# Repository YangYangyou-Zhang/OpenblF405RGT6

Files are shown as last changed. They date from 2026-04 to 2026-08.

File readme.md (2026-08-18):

包含一个5v-dcdc（bec），一个大疆高清图传（可拓展4G数传）直插口，sbus接口，elrs接收机接口，gps接口，
icm42605/42688p（mpu6500）加速度计，SPL06（bmp280）气压计，12组PWM输出（支持dshut）。
目前已编译和兼容APM、INAV、BF、px4平台代码迁移工作进行中。
考虑到市面上大部分F405固件因为flash阉割功能，本飞控APM固件已支持空速管，光流计（包含测距仪），板载计算机外部激光雷达或视觉定位。
It includes a 5v-dcdc (bec), a DJI high-definition image transmission (expandable to 4G data transmission) direct plug-in port, SBUS interface, ELRS receiver interface, and GPS interface,
ICM42605/42688P (MPU6500) accelerometer, SPL06 (BMP280) barometer, 12 sets of PWM outputs (supporting DSHUT).
Currently, it has been compiled and is compatible with APM, INAV, BF, PX4 platform.
Considering that most F405 firmware on the market has been disabled of its flash function, our flight control APM firmware now supports airspeed tubes, optical flow meters (including rangefinders), and external lidar or visual positioning for on-board computers.

请注意，此飞控的PX4功能由于F405芯片组的flash空间问题进行了阉割，导致此飞控的PX4功能仅可用于探索性研究。bootloader与APM共用
Please note that the PX4 functionality of this flight control using the F405 chip group's flash space has been阉ced, so this flight control's PX4 functionality is only suitable for exploratory research.The bootloader and APM share the same firmware.

请注意，使用APM固件时，如果不使用sbus接收机想要释放uart2号串口用于接elrs接收机或者数传链路设备时，
需要修改参数表BRD_ALT_CONFIG 引脚功能复用值为1（默认为0）来禁用sbus和释放uart为通用模式。
由于没有黑匣子芯片（如果没有安装SD卡）需要设置LOG_BACKEND_TYPE = 0，禁用日志功能。
Please note that when using APM firmware, if you want to free up UART2 serial port for connecting an ELRS receiver or a telemetry link device without using an SBus receiver,
The parameter table BRD_ALT_CONFIG needs to be modified by setting the pin function multiplexing value to 1 (default is 0) to disable SBus and release UART to general-purpose mode.
Due to the absence of a black box chip (if no SD card is installed), it is necessary to set LOG_BACKEND_TYPE = 0 to disable the logging function

PCB_BOM:https://oshwhub.com/yangyangyou/stm32f405_bl_matekf405_te_copy
请注意:此电路板为matekf405_te的改进版本，固件并不兼容。
Please note: This circuit board is an improved version of matekf405_te, and the firmware is not compatible.

PCB_BOM:https://oshwhub.com/yangyangyou/project_qvbuwenu
新增小型化穿越机专用飞控板卡（OpenblF405MINI系列），包含完整OSD、SD卡黑匣子和各种接口（所有接口均按照BF官方接口标准设计），包含大疆高清图传直插x1、GPS直插接口x1、四合一电子调速器直插、
I2C直插（空速管、测距仪）、串口直插x2（推荐elrs+数传电台）
New miniaturized flight controller board for FPV racing drones (OpenblF405MINI series), featuring full OSD, SD card black box, and various interfaces (all designed to BF official interface standards), including DJI HD video transmission direct plug x1, GPS direct plug x1, 4-in-1 ESC direct plug, I2C direct plug (airspeed sensor, rangefinder), serial port direct plug x2 (recommended ELRS + telemetry radio).

OpenblF405MINI
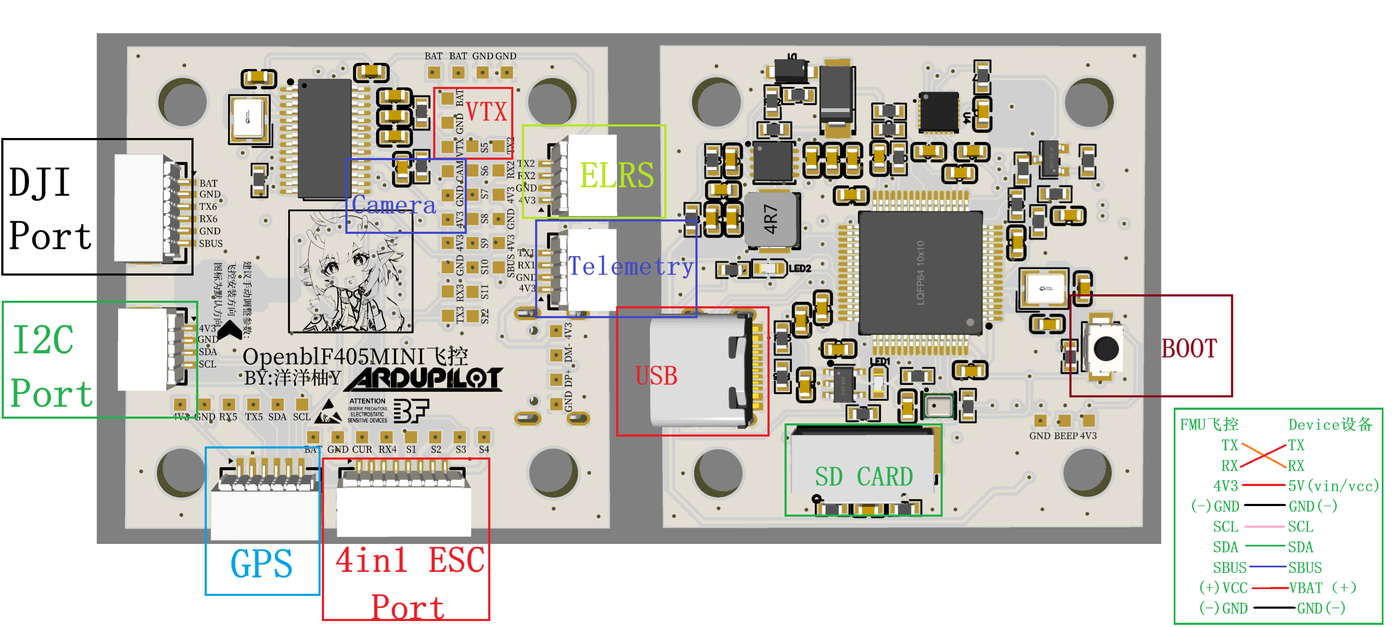
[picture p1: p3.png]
p3


OpenblF405RGT6
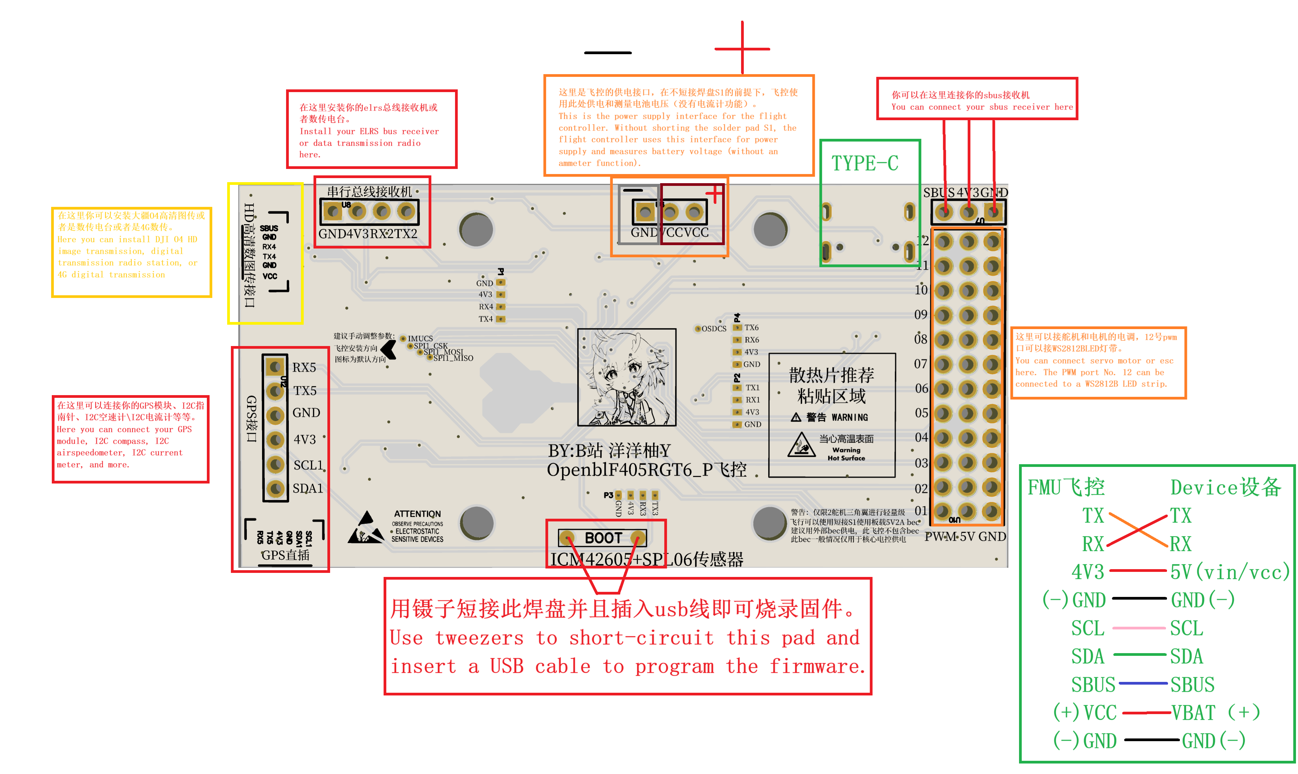
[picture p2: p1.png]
p1

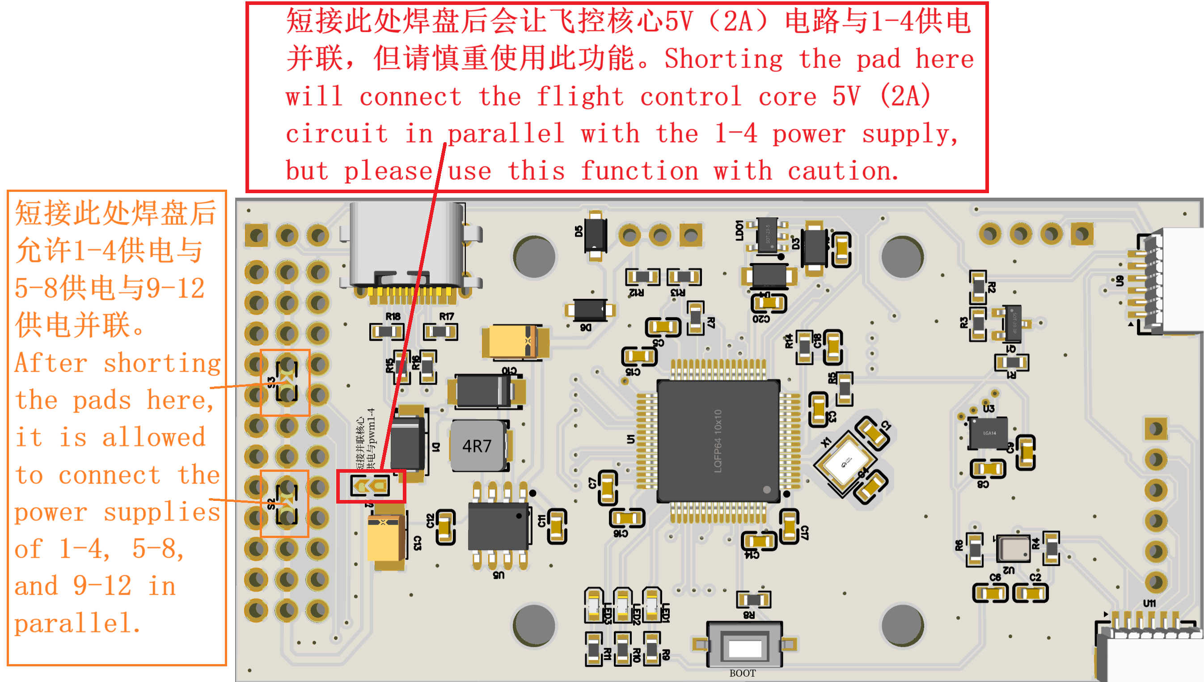
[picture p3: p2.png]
p2


代号说明Code Identifier Guide:
RGT6:40mmx80mm
MINI：40mmx40mm
(None)：mpu6500+bmp280
M：mpu6500+spl06
P：icm42605+spl06

如何快速入门APM：https://www.bilibili.com/video/BV1DJ7N61E1v

请注意，本设计为GPL3.0开源协议，允许商用，但需要标明原作者（洋洋柚/B站洋洋柚Y），无人机不是儿童玩具，使用时请遵守相关法律法规。
Please note that this design is under the GPL3.0 open-source protocol, which allows commercial use, but requires attribution to the original author (yangyangyou/bilibili 洋洋柚Y), and drones are not children's toys. Please abide by relevant laws and regulations when using it.

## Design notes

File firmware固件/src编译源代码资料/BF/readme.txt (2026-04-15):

# Update package list and upgrade system
sudo apt update && sudo apt upgrade

# Install basic compilation tools
# You need to install git (for cloning code), make (for building), clang (required for some tests), python, etc.
sudo apt -y install build-essential git curl clang-18 python3 python-is-python3

# Clone Betaflight source code
git clone https://github.com/betaflight/betaflight.git

# Enter the source code directory
cd betaflight

# Switch to a stable version (e.g. 4.5.3)
git checkout 4.5.3

# This command will automatically download and install the required toolchain
make arm_sdk_install

# After the first compilation or switching to a new branch, run this command to generate the default configuration for all target boards.
make configs

# Place the OpenblF405RGT6 folder into the ~/betaflight/src/config/configs directory, and then compile the OpenblF405RGT6 firmware
make config OpenblF405RGT6

# Find the compiled firmware betaflight_4.5.3_STM32F405_OpenblF405RGT6.hex in ~/betaflight/obj

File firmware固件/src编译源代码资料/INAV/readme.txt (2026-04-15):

# Clone iNav source code
git clone https://github.com/iNavFlight/inav.git
cd inav

# Create a build directory and initialize CMake
mkdir build && cd build
cmake

# Move the OpenblF405RGT6 folder to the directory ~/inav/src/main/target/.
# Compile firmware
cd ~/inav

# 1.  Create a build directory
mkdir -p build

# 2.  Run CMake configuration
cmake -B build -DCMAKE_TOOLCHAIN_FILE=cmake/toolchain-arm-none-eabi.cmake

# 3.  Compile your target (-j4 to compile with 4 CPU threads)
cmake --build build --target OpenblF405RGT6 -j4

# Check firmware
# Typically located in the ~/inav/build directory

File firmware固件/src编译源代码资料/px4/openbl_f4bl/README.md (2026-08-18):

# openbl_f4bl — PX4 固件编译说明

## 硬件平台
- **MCU**: STM32F405RGT6 (Cortex-M4, 168MHz, 1024KB Flash)
- **IMU**: MPU6500 (SPI1, CS=PA4, ROTATION_ROLL_180)
- **气压计**: BMP280 / SPL06 (I2C1, PB8/PB7)
- **OSD**: AT7456E (SPI1, CS=PB12)
- **LED**: PA14 (蓝), PA13 (绿)

## Flash 布局

| 区域 | 起始地址 | 大小 |
|---|---|---|
| Bootloader | `0x08000000` | 64KB (APM bootloader, ~16KB 实际) |
| 参数存储 | `0x08004000` | 16KB |
| 固件 | `0x08010000` | 960KB |

## 编译

### 1. 部署板级配置

```
cp -r openbl_f4bl /home/<username>/PX4-Autopilot/boards/openbl/f4bl
```

### 2. 应用框架补丁

PX4 框架 `io_timer.c` 需要打补丁以支持 TIM1/TIM8 高级定时器的互补通道 (CHxN) 输出。

文件: `platforms/nuttx/src/px4/stm/stm32_common/io_pins/io_timer.c`

补丁文件: `patches/io_timer.c` (完整的修改后文件)

修改内容:
- 在 `io_timer_channel_init()` 中，CCER 配置后添加互补输出使能 (CCxNE) 和互补极性 (CCxNP) 位
- 仅对 TIM1 和 TIM8 生效

```bash
cp patches/io_timer.c /home/<username>/PX4-Autopilot/platforms/nuttx/src/px4/stm/stm32_common/io_pins/io_timer.c
```

### 3. 编译固件

```bash
cd /home/<username>/PX4-Autopilot
make openbl_f4bl_default
```

### 4. 生成 HEX

```bash
arm-none-eabi-objcopy -O ihex build/openbl_f4bl_default/openbl_f4bl_default.elf openbl_f4bl_default.hex
```

## 产物

| 文件 | 说明 |
|---|---|
| `openbl_f4bl_default.bin` | 原始固件 (~888KB) |
| `openbl_f4bl_default.px4` | PX4 固件包 |
| `openbl_f4bl_default.hex` | Intel HEX 格式 |

## 修改文件清单

### 板级配置 (`boards/openbl/f4bl/`)

| 文件 | 说明 |
|---|---|
| `default.px4board` | PX4 模块/驱动/串口映射配置 |
| `firmware.prototype` | 固件元数据 (board_id=18880) |
| `init/rc.board_defaults` | 默认参数 (BAT, ATT_EN, SYS_HAS_MAG) |
| `init/rc.board_sensors` | 传感器启动脚本 (MPU6500, BMP280, SPL06) |
| `init/rc.board_extras` | OSD 启动脚本 |
| `src/board_config.h` | GPIO/ADC/PWM/LED 定义, BOARD_NUM_IO_TIMERS=3 |
| `src/timer_config.cpp` | PWM 定时器映射 (TIM8+TIM1+TIM2, 4 通道) |
| `src/spi.cpp` | SPI 总线设备声明 (MPU6500, OSD, SD) |
| `src/i2c.cpp` | I2C1 总线声明 |
| `src/init.c` | 板级初始化 (SPI, SD, Flash参数, ADC) |
| `src/led.c` | LED 控制 (PA14/PA13, 低电平有效) |
| `src/usb.c` | USB VBUS (始终报告在线) |
| `src/CMakeLists.txt` | 驱动编译定义 |
| `nuttx-config/include/board.h` | NuttX 时钟/引脚复用 (8MHz→168MHz) |
| `nuttx-config/include/board_dma_map.h` | DMA 流/通道分配 |
| `nuttx-config/nsh/defconfig` | NuttX 内核配置 |
| `nuttx-config/scripts/script.ld` | 链接脚本 (flash: 0x08010000, 960K) |

### PX4 框架修改

| 文件 | 说明 |
|---|---|
| `platforms/nuttx/src/px4/stm/stm32_common/io_pins/io_timer.c` | 添加 TIM1/TIM8 互补通道使能 (CCxNE+CCxNP) |

### NuttX Kconfig 路径修复 (编译环境相关)

| 文件 | 说明 |
|---|---|
| `platforms/nuttx/NuttX/apps/Kconfig` | 将 `/home/openbl/` 替换为 `/home/<username>/` |
| `platforms/nuttx/NuttX/apps/*/Kconfig` | 同上 (20 个子目录) |

## PWM 输出

| 通道 | 引脚 | 定时器 | 说明 |
|---|---|---|---|
| 1 | PC9 | TIM8_CH4 | 电机 1 |
| 2 | PC8 | TIM8_CH3 | 电机 2 |
| 3 | PB15 | TIM1_CH3N | 电机 3 (互补通道, 需框架补丁) |
| 4 | PA8 | TIM1_CH1 | 电机 4 |

## 串口映射

| 硬件 | 设备 | PX4 命名 |
|---|---|---|
| USART2 (PA2/PA3) | ttyS1 | TEL1 |
| UART5 (PC12/PD2) | ttyS2 | GPS1 |

## Bootloader

APM bootloader，基于 `hwdef-bl.dat` 编译。与 PX4 协议兼容。

构建:
```bash
cd /home/<username>/ardupilot
./waf configure --board OpenblF405RGT6 --bootloader
./waf bootloader
```

预编译 bootloader: `extras/openbl_f405_bootloader.bin`

## 烧录

```bash
# 首次: bootloader + 固件
STM32_Programmer_CLI -c port=usb1 -w extras/openbl_f405_bootloader.bin 0x08000000
STM32_Programmer_CLI -c port=usb1 -w openbl_f4bl_default.bin 0x08010000

# 仅固件 (QGC USB 直刷)
```

或 SD 卡: 将 `.px4` 复制到 SD 卡根目录，bootloader 自动刷写。

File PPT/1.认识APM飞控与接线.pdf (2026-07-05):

# 认识飞控板卡与接线

## 这里以OpenblF405RGT6为例

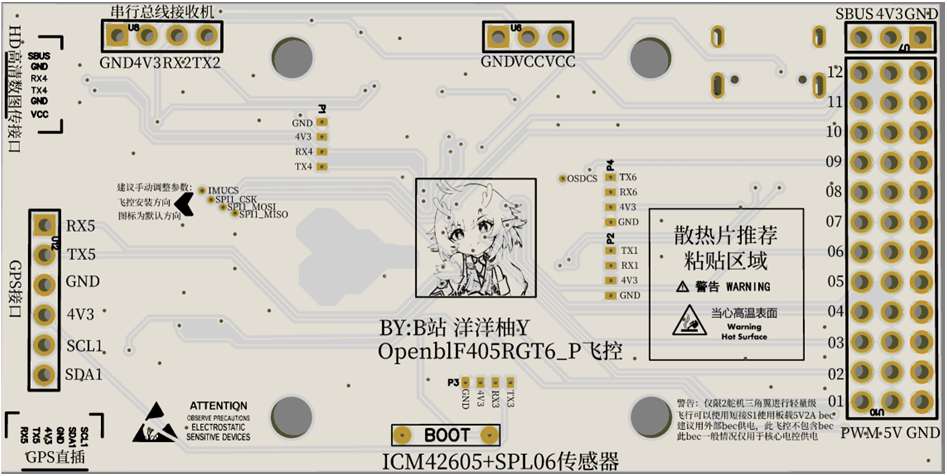
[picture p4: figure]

# 认识飞控板卡与接线

这里以OpenblF405RGT6为例

包含一个5v-dcdc（bec），一个大疆高清图传（可拓展4G数传）直插口，sbus接口， elrs接收机接口，gps接口，icm42605/42688p（mpu6500）加速度计，SPL06 （bmp280）气压计，12组PWM输出（支持dshut）。目前已编译和兼容APM、INAV、

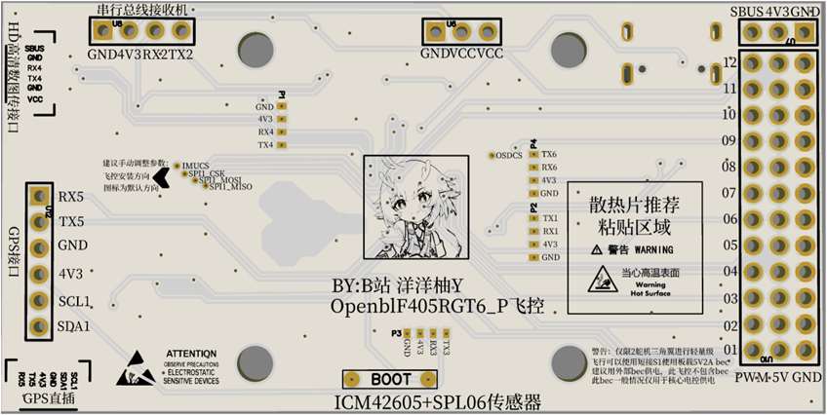
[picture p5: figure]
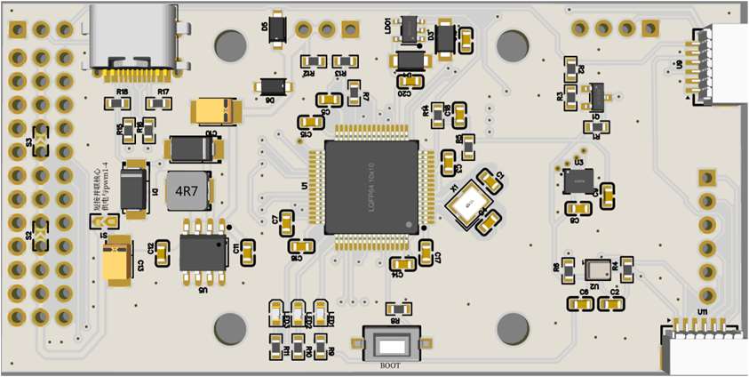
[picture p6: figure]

BF平台，px4平台代码迁移工作进行中。考虑到市面上大部分F405固件因为flash阉割 功能，本飞控APM固件已支持空速管，光流计（包含测距仪），板载计算机外部激光 雷达或视觉定位。

此飞控板卡完全开源，在符合开源协议且遵守当地相关法律法规的前提下可以随意使 用。

# 插口、焊盘、过孔焊盘（2.54）

2.54过孔焊盘可以直接焊接，
或者也可以焊接排针用于作为

支持端口使用，适合新手使用。

插口一般指的是可以直接将

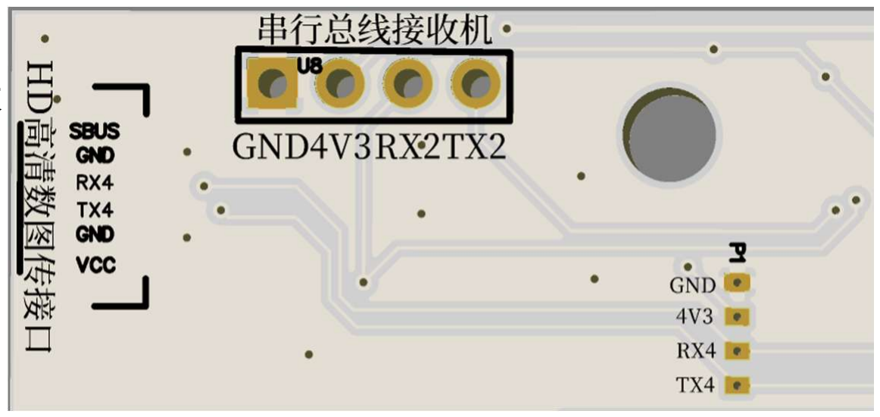
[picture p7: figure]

端子线排插插入的插口，一般
不需要焊接

普通焊盘只能直接焊接，
不适合焊接技术差的新手使用。

# 推荐新手使用过孔焊盘（2.54mm）

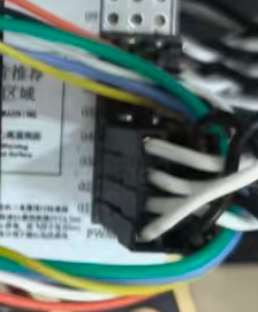
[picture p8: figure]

2.54过孔焊盘可以直接焊接，
或者也可以焊接排针用于作为
支持端口使用，适合新手使用。

焊接难度相对较低，对新手比较友
好，可以购买排针焊接到2.54过孔
焊盘使得可以直插设备。

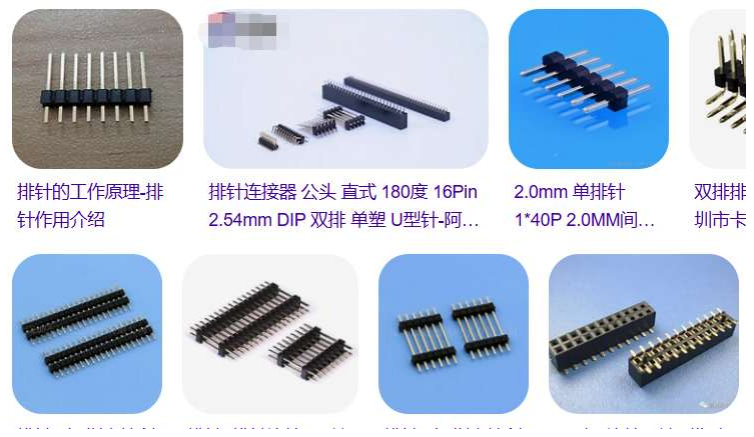
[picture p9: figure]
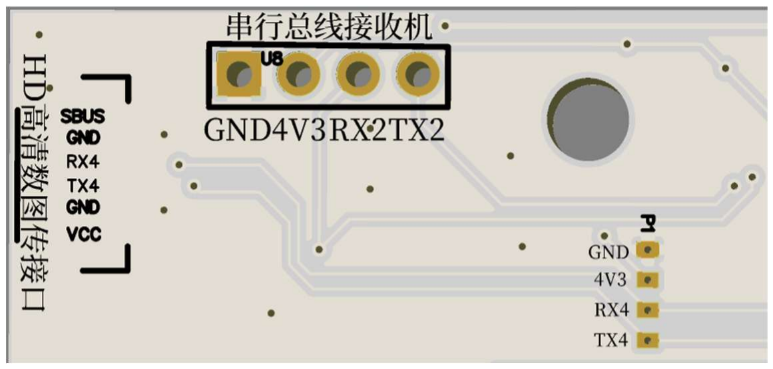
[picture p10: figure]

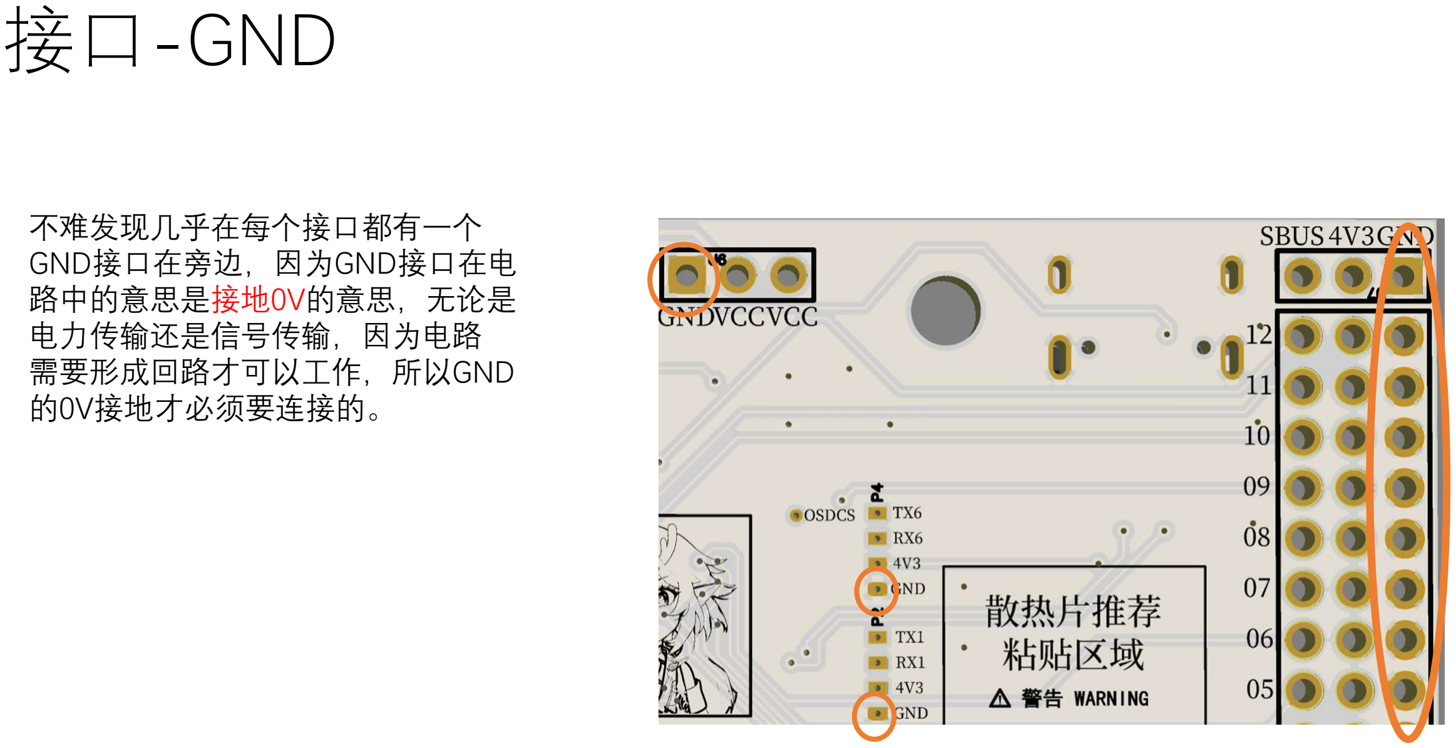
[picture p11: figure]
接口-GND; 不难发现几乎在每个接口都有一个 GND接口在旁边，因为GND接口在电 路中的意思是接地0V的意思，无论是 电力传输还是信号传输，因为电路 需要形成回路才可以工作，所以GND 的0V接地才必须要连接的。

# 接口-VBAT/VCC

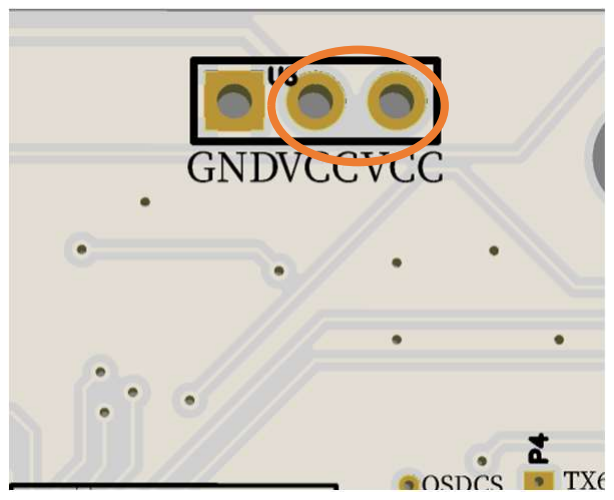
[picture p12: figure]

这个接口的名称在各个飞控板卡
的名字可能不同，例如这里叫VCC，
有些飞控叫vbat、bat，这个接口的
意思是指连接到动力电池的正极，
通常用于监测飞控电压，一般飞控
也会使用这个接口对飞控板卡供电，
同时当某些图传或者电台需要较高
的供电电压时，也会连接到这个接
口。

# 接口-5V

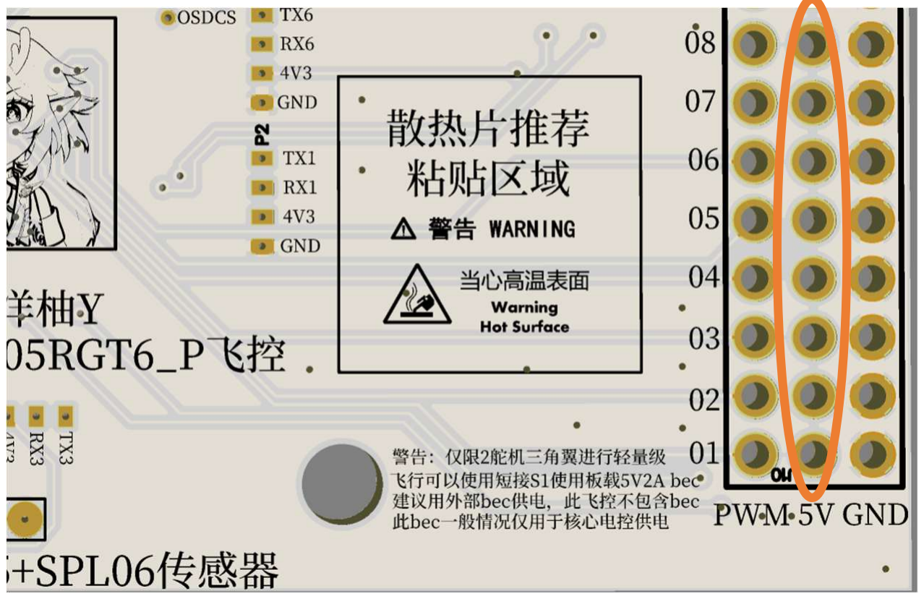
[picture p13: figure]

这个接口一般会由DCDC(bec)电路
提供+5V的电压，通常用于连接舵
机、电调等设备,但在部分飞控没
有bec电路时例OpenblF405RGT6 ，
需要连接带BEC功能的电调才可以
对舵机进行正常供电。

# 接口-4V3

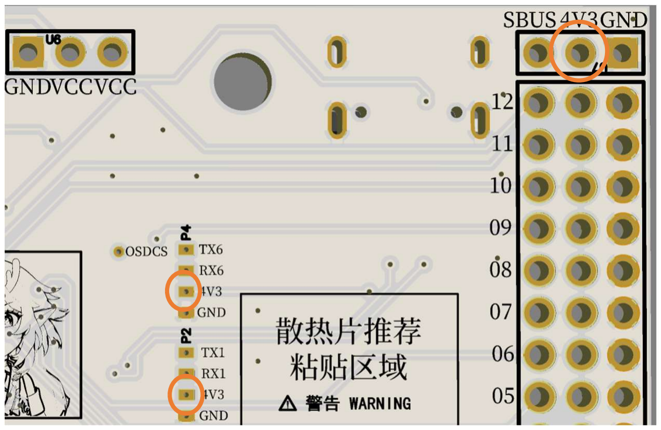
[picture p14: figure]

这个接口源于和5V同源且可以直接当
作5V接口使用，但这个接口一般在仅
连接电脑usb（不连接电池）时也会
供电，我们通常希望在调参时电机舵
机不会自己转动，但所有的传感器和
其他设备全部都要正常工作，因此会
在DCDC电路的5V接一个二极管到这
个4V3接口，因为二极管有压降，所
以电压略低于5V，如果仅使用usb连
接，一般5V电路不会工作（如舵机），
但4V3电路可以工作（如GPS、接收
机）。

# 接口-PWM、s1s2s3s4…

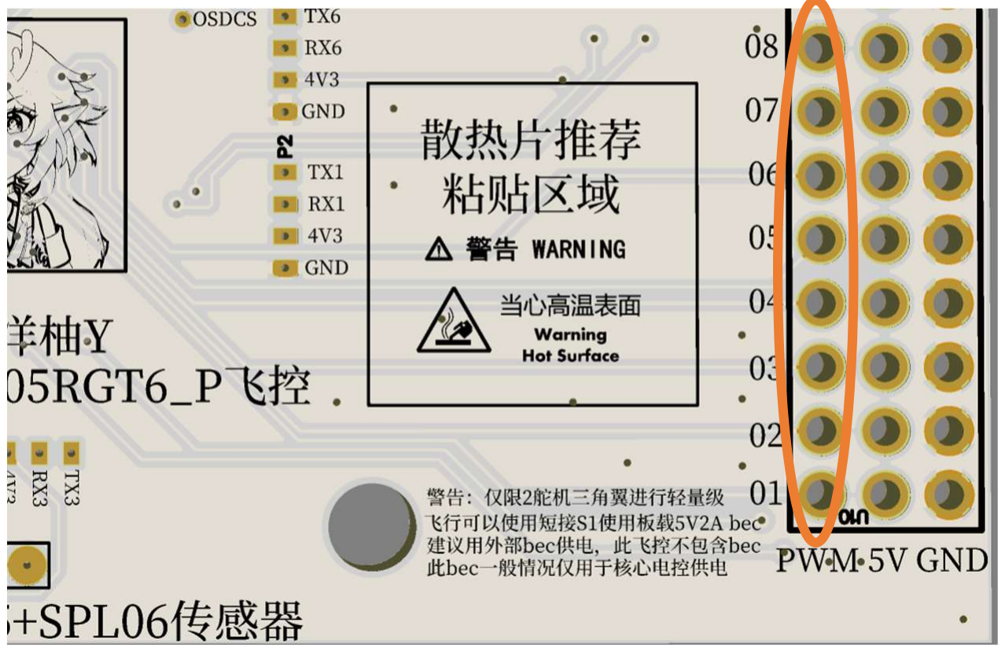
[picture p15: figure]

这个接口一般是连接舵机或者电调
的信号线使用，一般会输出PWM
波或者dshut信号用于飞控给舵机
和电调发出信号使得他们保持正常
工作。

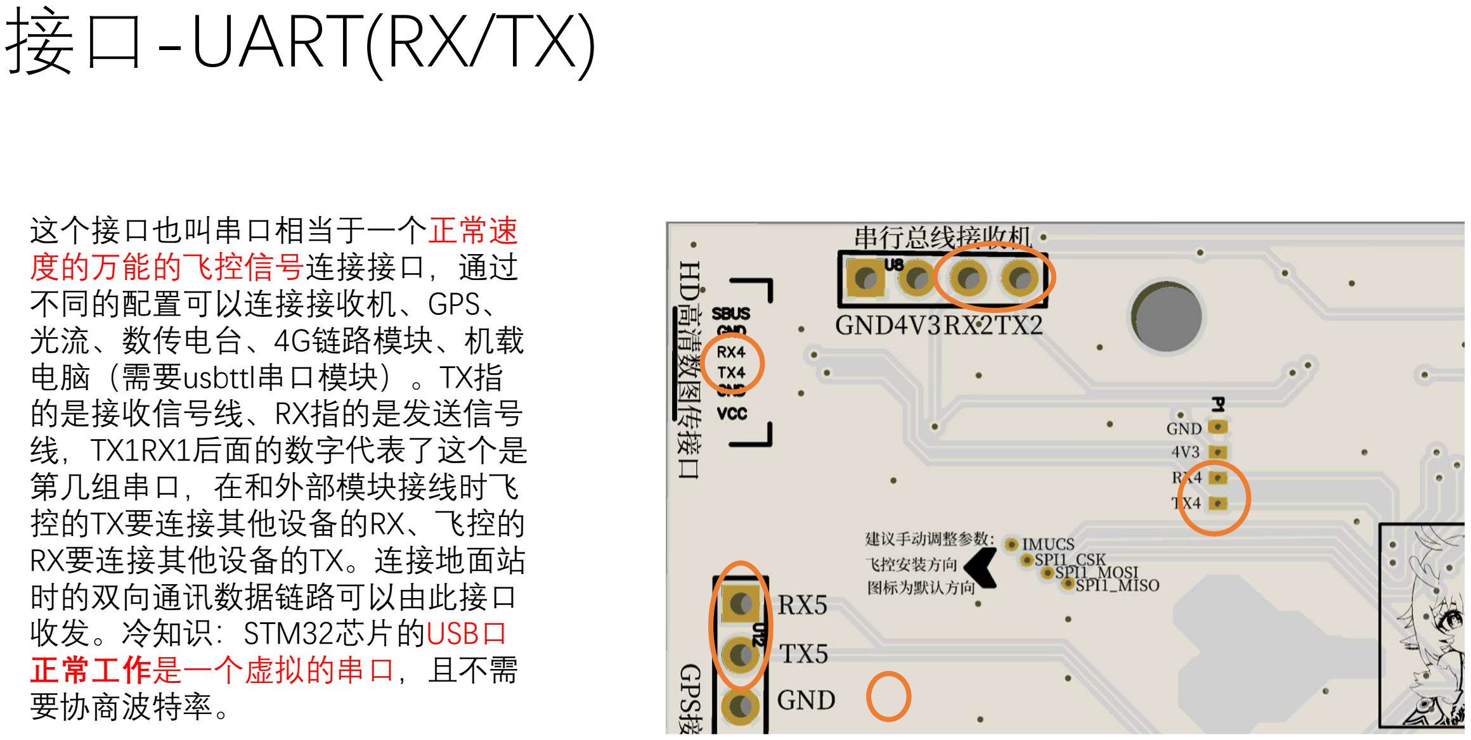
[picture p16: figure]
接口-UART(RX/TX); 这个接口也叫串口相当于一个正常速 度的万能的飞控信号连接接口，通过 不同的配置可以连接接收机、GPS、 光流、数传电台、4G链路模块、机载 电脑（需要usbttl串口模块）。TX指 的是接收信号线、RX指的是发送信号 线，TX1RX1后面的数字代表了这个是 第几组串口，在和外部模块接线时飞 控的TX要连接其他设备的RX、飞控的 RX要连接其他设备的TX。连接地面站 时的双向通讯数据链路可以由此接口 收发。冷知识：STM32芯片的USB口 正常工作是一个虚拟的串口，且不需 要协商波特率。

# 接口-SBUS(反相电平RX)

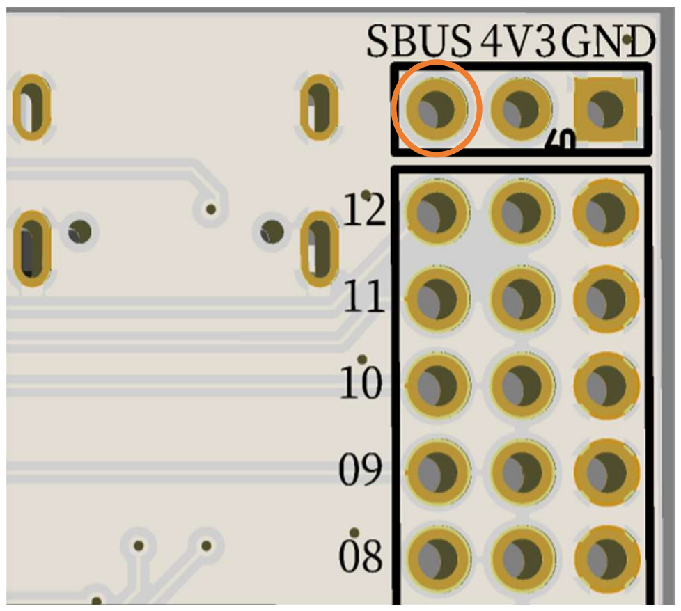
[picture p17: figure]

这个接口通常用来连接sbus接收机信
号，但其实他完全相当于一个把输入
信号反相电平之后输出给的RX信号线，
具体是哪个UART的RX需要看飞控设
计（列如 OpenblF405RGT6 就是反相
电平的RX2）。

# 接口-I2C(SCL/SDA)

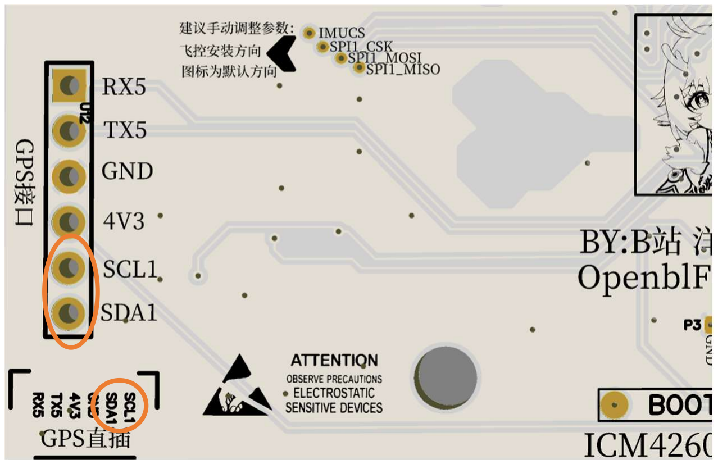
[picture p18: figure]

这个接口相当于一个较快速度的万能
的飞控信号连接接口，通过不同的配
置可以连接指南针（GPS的罗盘）、
空速管、气压计、测距仪、电流计等
等设备（但需要设备支持I2C）。
SCL为时钟线，SDA为双向数据线，
I2C为地址寻址的总线通讯协议，所以
支持不同地址（类型）多设备并联，
例如可以把指南针和气压计和测距仪
直接并联在一起。
飞控的SCL接设备的SCL，飞控的SDA
接设备的SDA。
冷知识，其实这个叫IIC或者I²C，而不
叫I2C，只是平时输入法写平方不方便
罢了。

# 接口-SPI(CSK/MOSI/MISO+CS)不常用

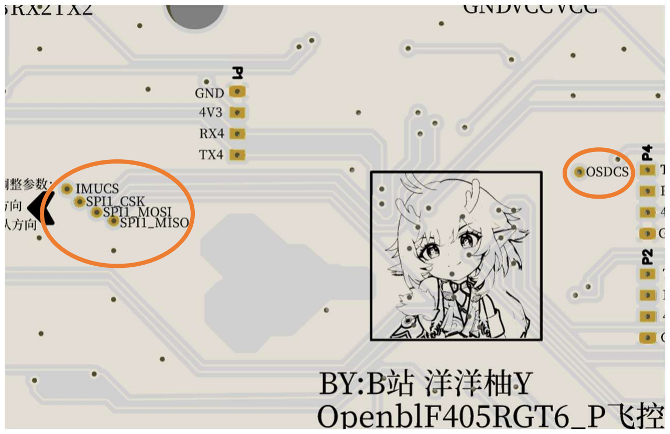
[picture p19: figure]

这个接口相当于一个高速度的万能的
飞控信号连接接口，通过不同的配置
可以连接IMU、SD卡、模拟图传的
OSD模块。
CSK为时钟线，MOSI为飞控输出信号，
MISO为设备输出信号，CS为设备使
能线，SPI的速度相对快，一般只有
CS线是独立连接到外围模块，其他线
全部并联，飞控通过CS线告诉外围设
备谁该工作了。
飞控的CSK接设备的CSK ，飞控的
MOSI接设备的MOSI ，飞控的MISO接
设备的MISO ，飞控的CS接设备的CS 。

# 模拟摄像头CAM与模拟图传接口VTX

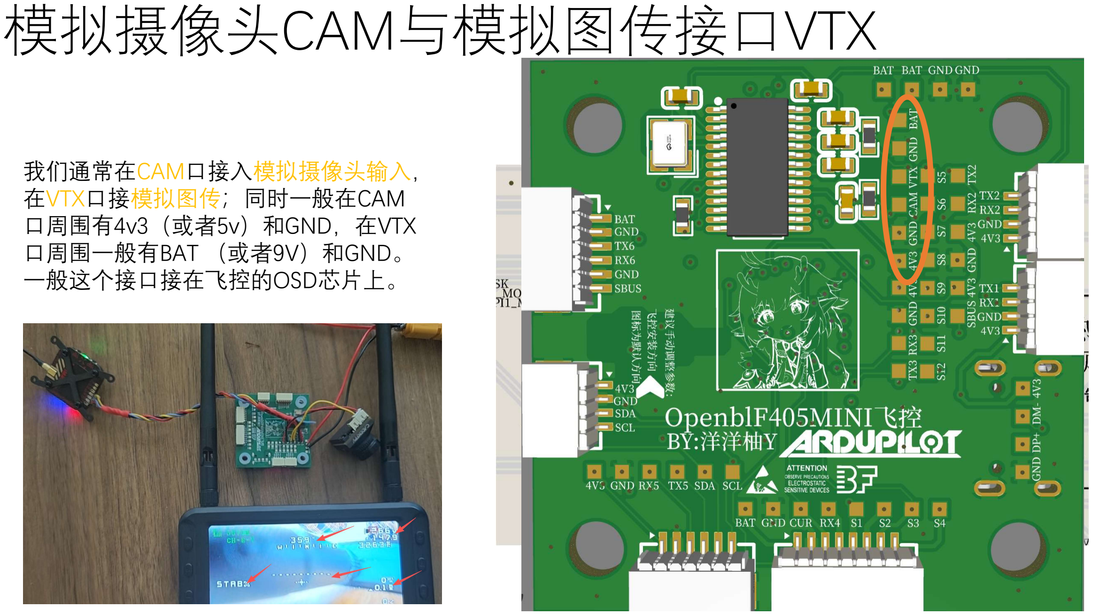
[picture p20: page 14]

我们通常在CAM口接入模拟摄像头输入，
在VTX口接模拟图传；同时一般在CAM
口周围有4v3（或者5v）和GND，在VTX
口周围一般有BAT （或者9V）和GND。
一般这个接口接在飞控的OSD芯片上。

# BOOT按钮与USB烧录固件

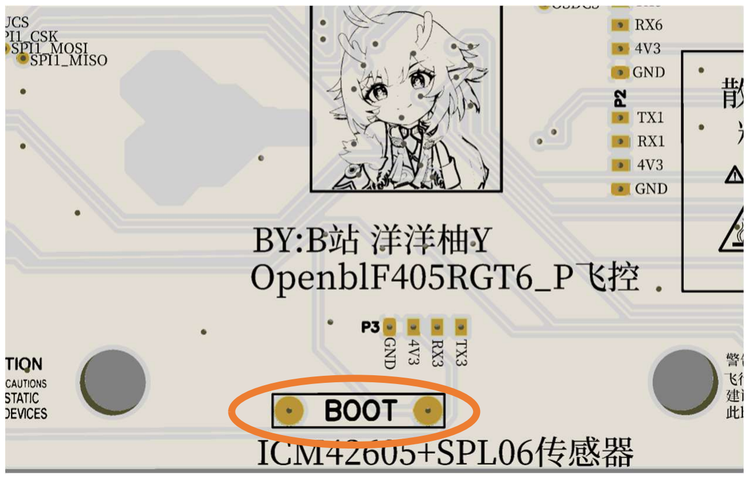
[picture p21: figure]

首先把整个飞控全部断电，随后按
下BOOT按钮，如果没有焊接按钮，
可以使用镊子短接住BOOT按钮的
同时然后插上USB线，这个时候飞
控会进入DFU固件烧录模式。

# 固件烧录工具

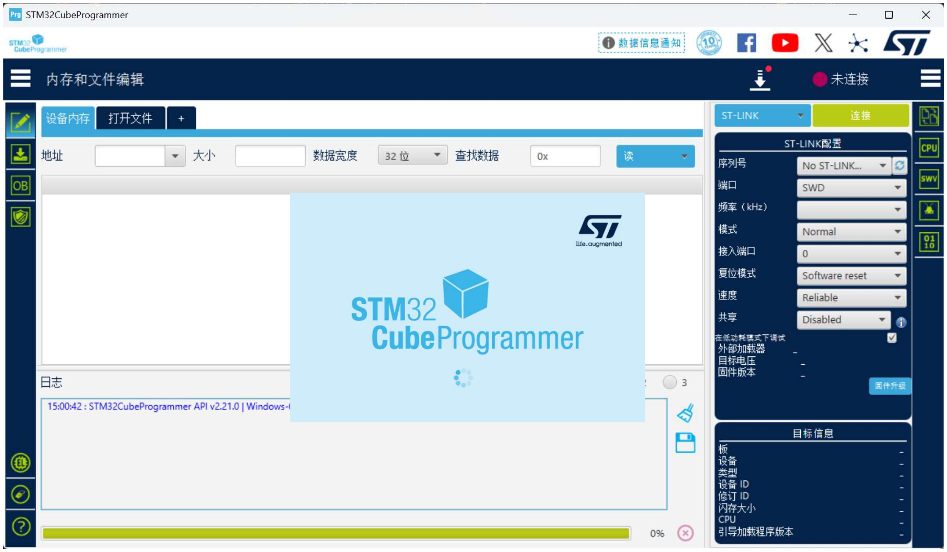
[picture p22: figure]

STM32CubeProgrammer

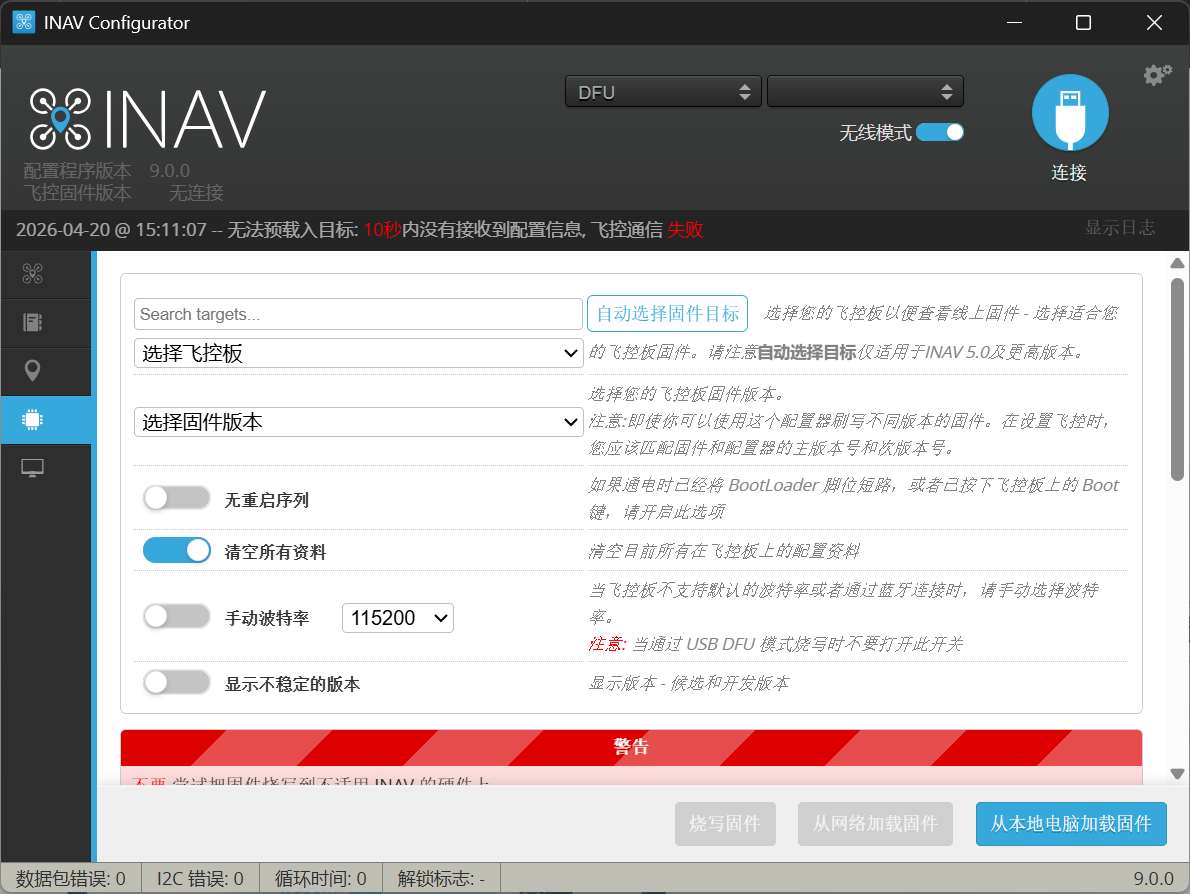
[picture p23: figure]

（安装麻烦，不推荐） | INAV地面站

https://github.com/iNavFlight/inav-configurator/releases

# 固件烧录工具INAV地面站

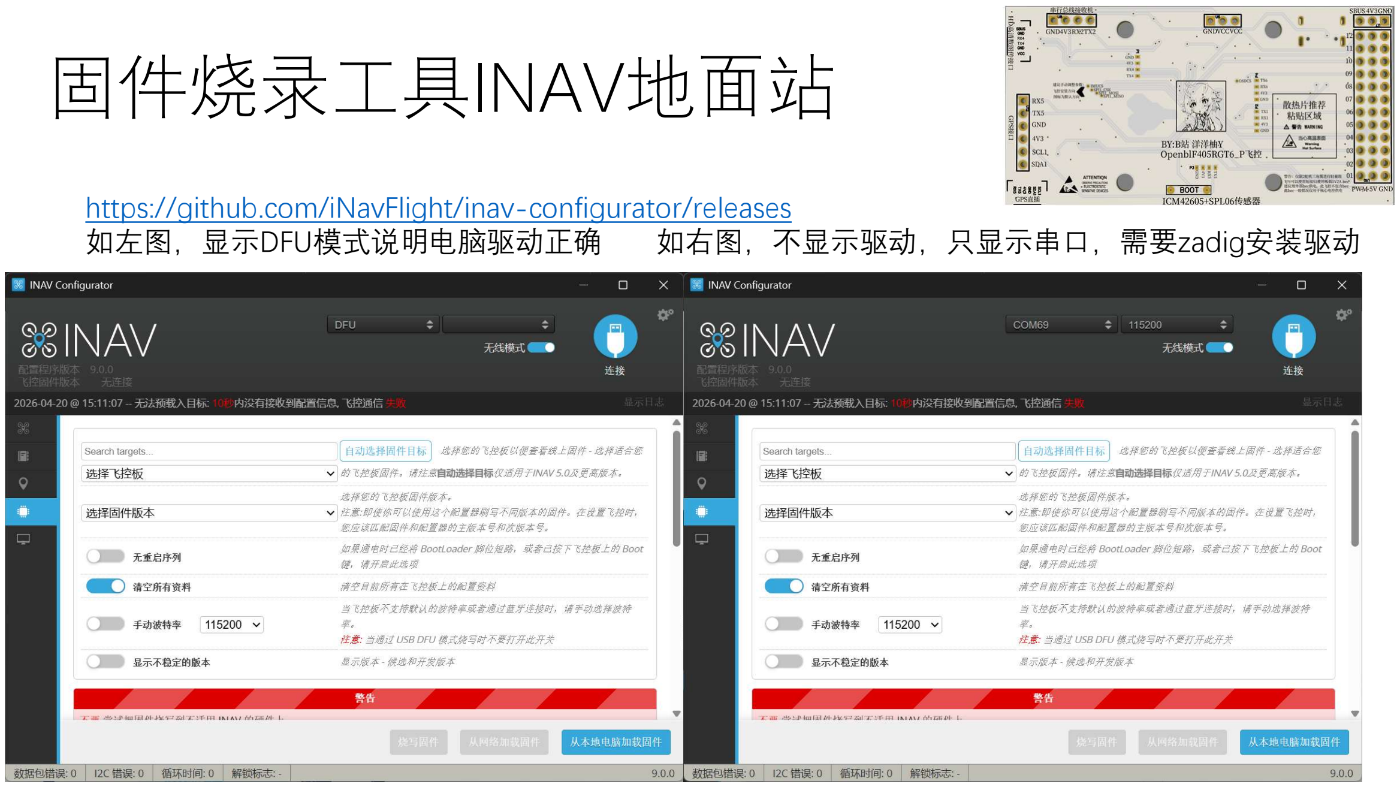
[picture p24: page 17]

https://github.com/iNavFlight/inav-configurator/releases
如左图，显示DFU模式说明电脑驱动正确 如右图，不显示驱动，只显示串口，需要zadig安装驱动

# 固件烧录工具zadig更新驱动

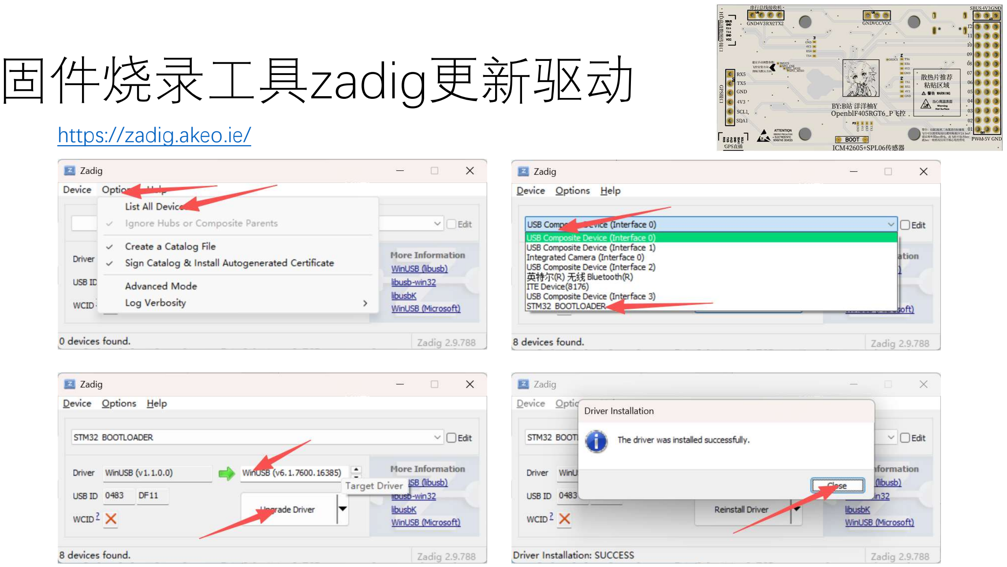
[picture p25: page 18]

https://zadig.akeo.ie/

# 固件烧录工具INAV地面站

1.选择从本地加载固件，然后找到要烧录的
HEX文件。
2.点击烧录固件将固件烧录至飞控。
3.烧录完成后将飞控拔下并且重新连接（不用
再按BOOT按钮）。

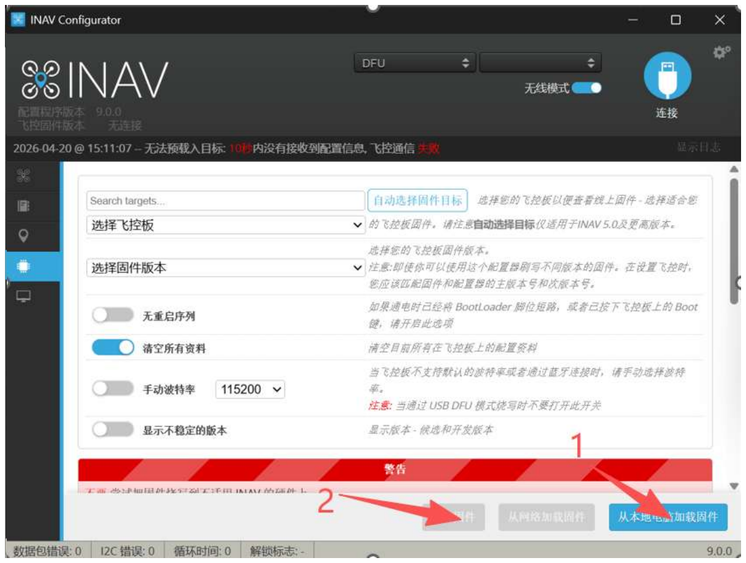
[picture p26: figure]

# 感谢观看~

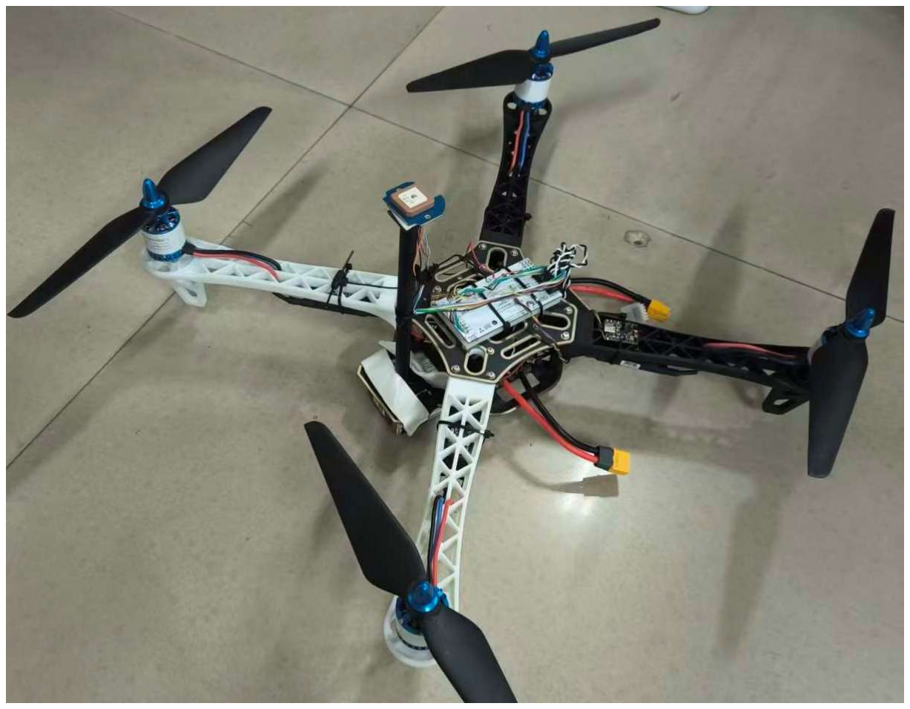
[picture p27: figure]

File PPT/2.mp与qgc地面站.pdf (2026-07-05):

# MP与QGC地面站

无人机不是儿童玩具，请务必注意安全，遵守相关法律法规。


## QGC与MP地面站

- MP地面站，全称Mission Planner， 是早期APM飞控的主要调参、任务
规划与教学软件，可以为PX4和APM 飞控调参。


- QGC地面站，全称QGroundControl， 属于更现代的飞控调参与任务规划软
件，同样也可以为PX4和APM飞控调
参。
- 切记，无论是什么地面站，都是以
mavlink连接飞控，如何图形化界面
本质都是修改参数表实现调参。

## MP地面站下载

- https://ardupilot.org/planner/docs/mission-planner-installation.html


## MP地面站地图设置


- 一开始不显示地图，需要修改地图来源
- （默认是谷歌，国内无法访问）

## MP地面站地图设置

- 一开始不显示地图，需要修改
地图来源


- （默认是谷歌，国内无法访问）
- 修改为国内可访问地图后恢复
卫星地图显示

## MP地面站显示设置

- 快速显示栏设置，左键双击快速显示栏项目，建议添加一个 卫星数量来查看GPS搜星状态，其他选项按需添加。



## MP地面站连接飞控

- 插入飞行器板卡，
- 选择飞行器板卡的串口，
- 等待数据加载完成。
- 请务必使用typec数据线，不
要用电源线。


## QGC地面站下载


- https://qgroundcontrol.com/


## QGC地面站姿态球

- 推荐调节一下姿态球为常用
画面模式。
- 1.右键姿态球
- 2.选择模式
- 3.锁定



## QGC地面站连接飞控

- 插入飞控，QGC将会自动寻
找串口并且连接，首次连接
可能会报出警告。
- 请务必使用typec数据线，不
要用电源线。

## QGC不识别飞控zadig更新驱动


https://zadig.akeo.ie/


# 感谢观看

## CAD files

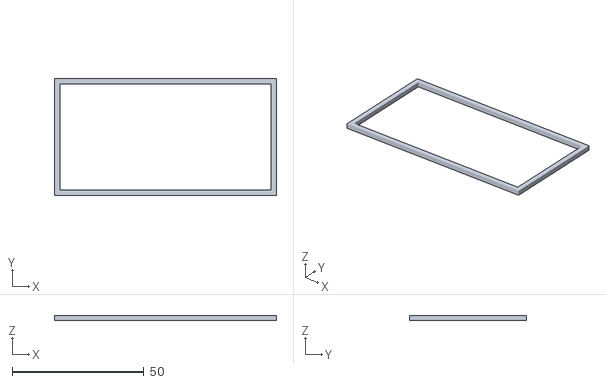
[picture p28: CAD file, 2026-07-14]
STL图纸/钢网框4-8.STL
84.2 x 44.2 x 2.00

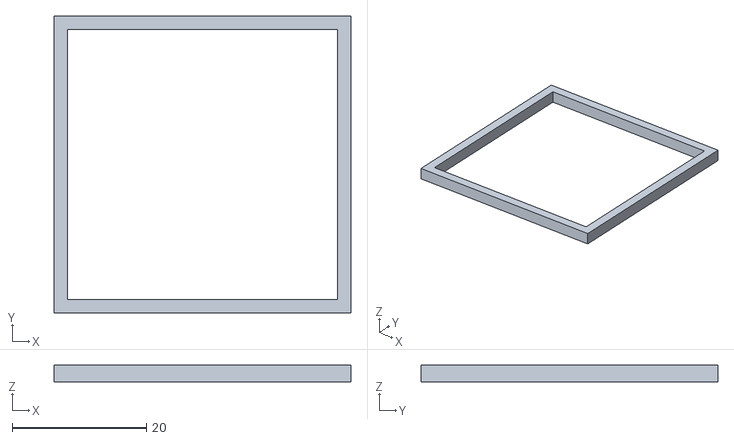
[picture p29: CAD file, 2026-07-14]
STL图纸/钢网框4-4.STL
44.2 x 44.2 x 2.50

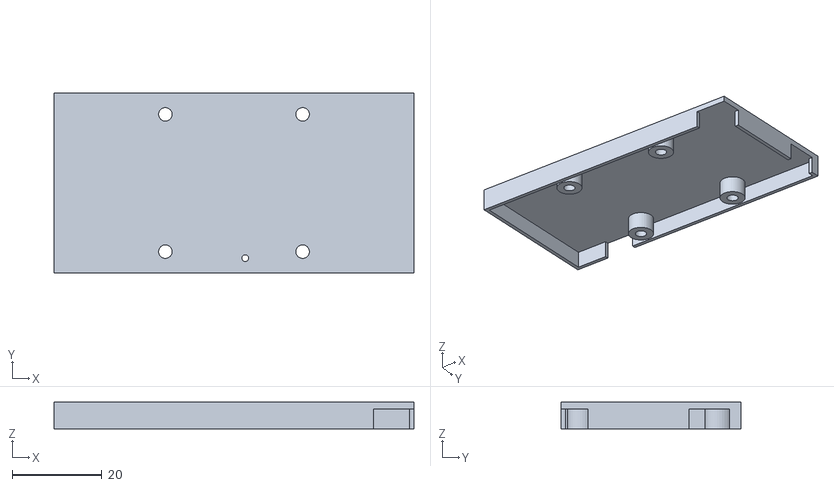
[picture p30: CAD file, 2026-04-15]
STL图纸/STM32F405_OpenblF405RGT6加固.STL
80.0 x 40.0 x 6.00

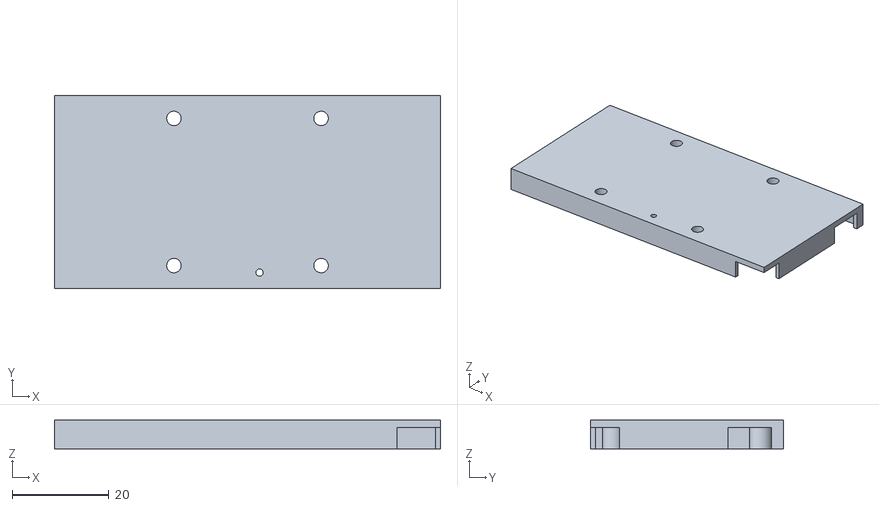
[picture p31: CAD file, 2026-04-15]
STL图纸/STM32F405_OpenblF405RGT6.STL
80.0 x 40.0 x 6.00

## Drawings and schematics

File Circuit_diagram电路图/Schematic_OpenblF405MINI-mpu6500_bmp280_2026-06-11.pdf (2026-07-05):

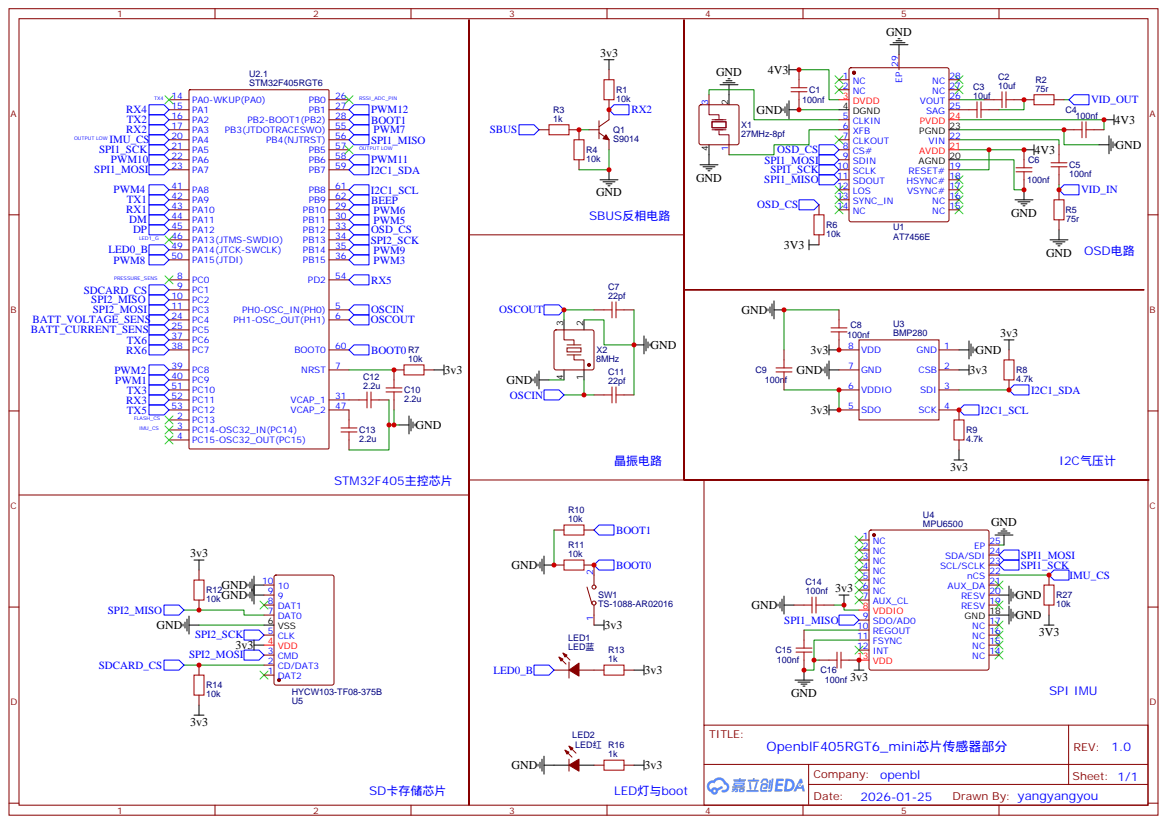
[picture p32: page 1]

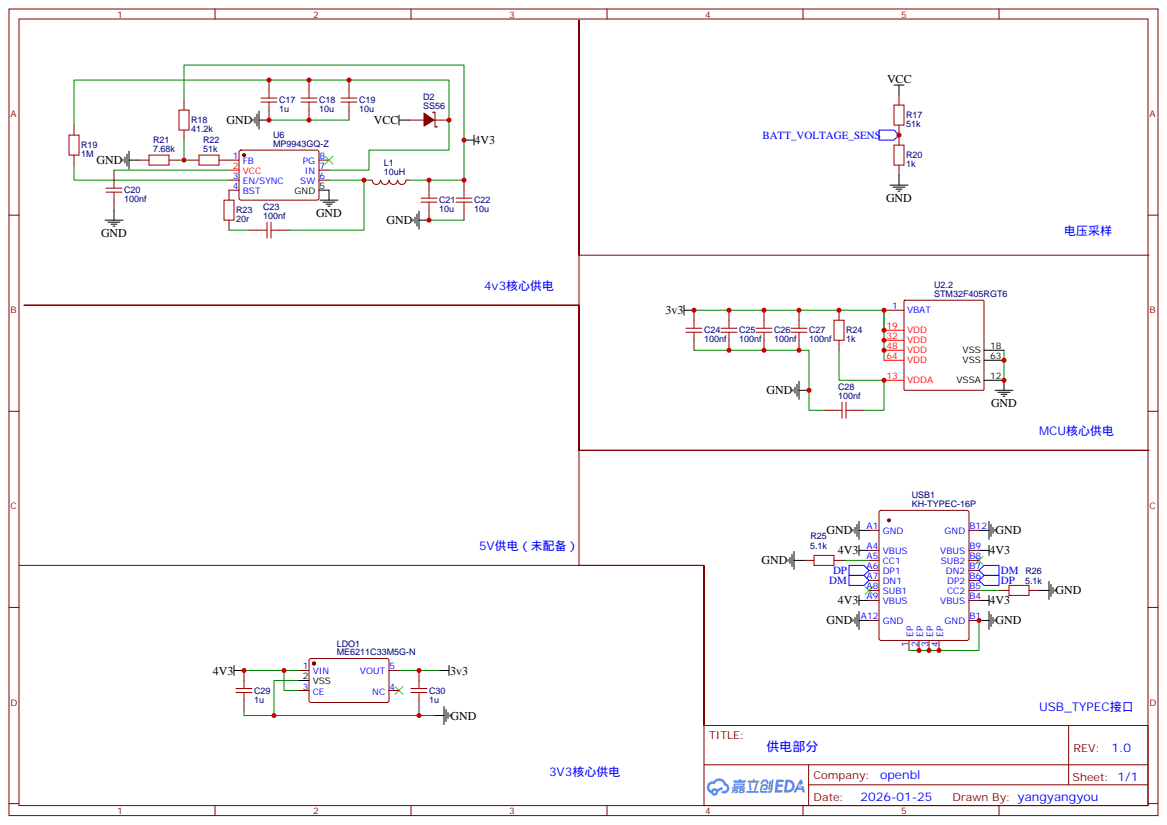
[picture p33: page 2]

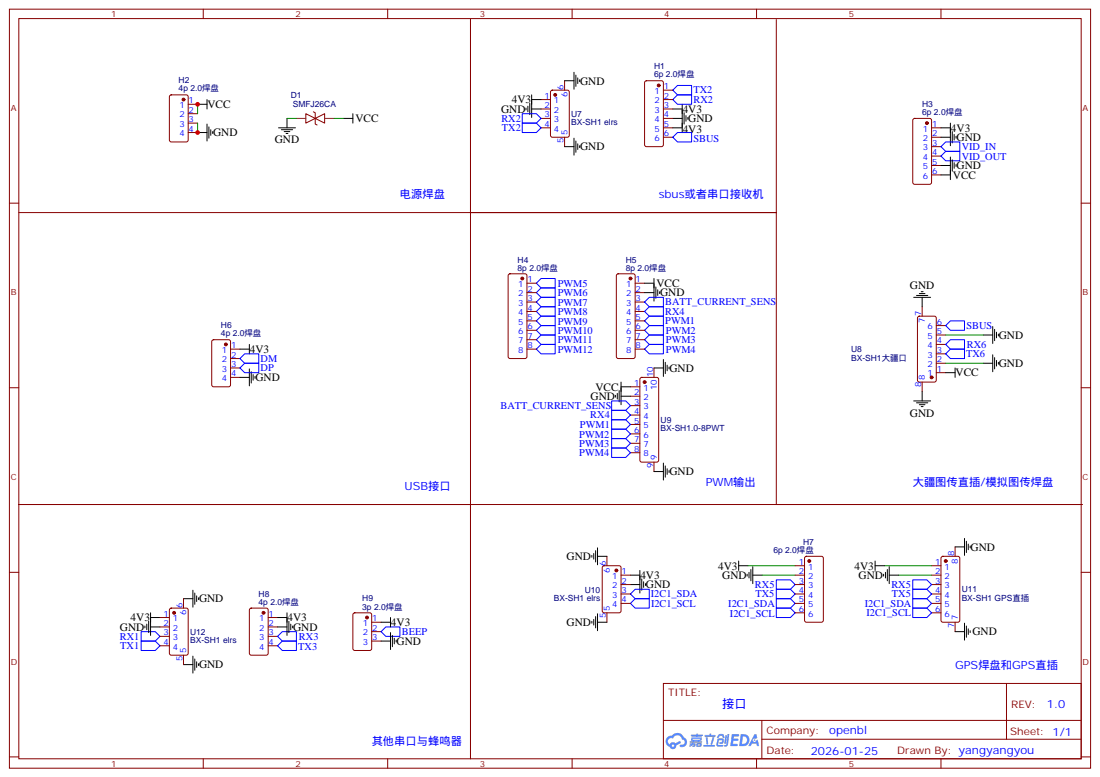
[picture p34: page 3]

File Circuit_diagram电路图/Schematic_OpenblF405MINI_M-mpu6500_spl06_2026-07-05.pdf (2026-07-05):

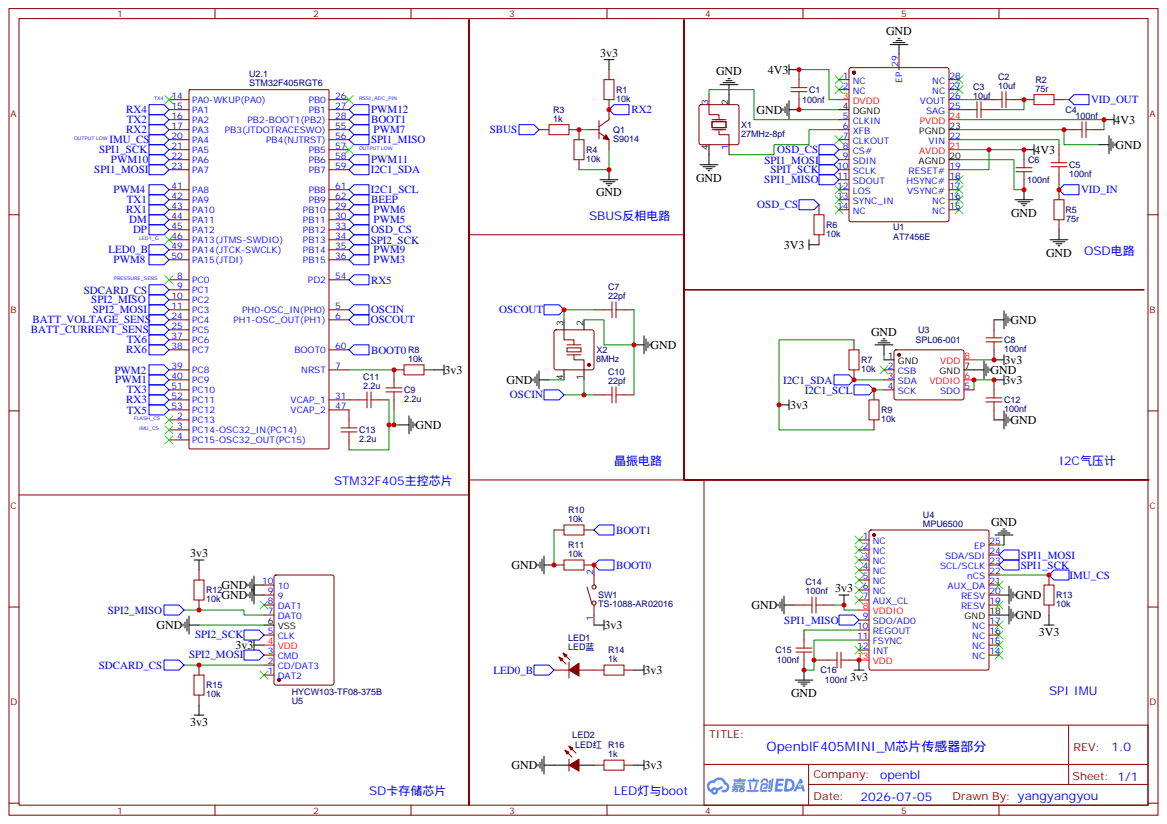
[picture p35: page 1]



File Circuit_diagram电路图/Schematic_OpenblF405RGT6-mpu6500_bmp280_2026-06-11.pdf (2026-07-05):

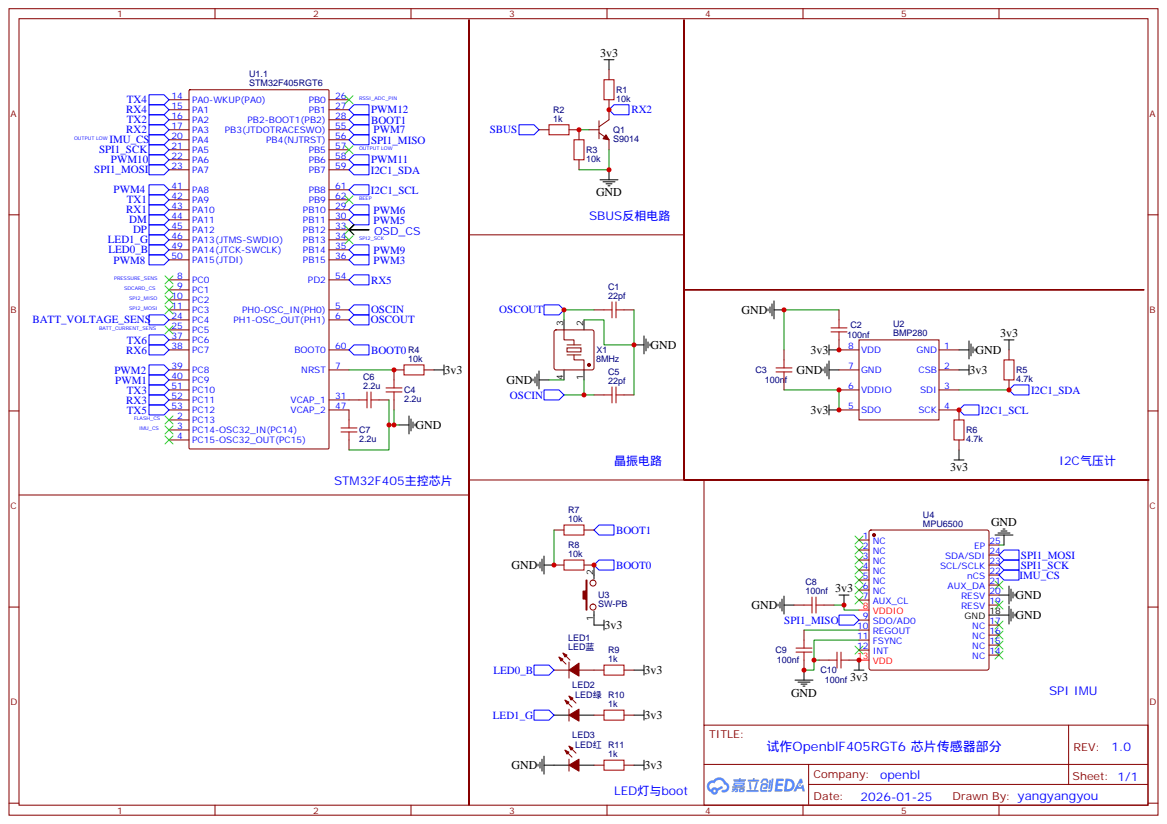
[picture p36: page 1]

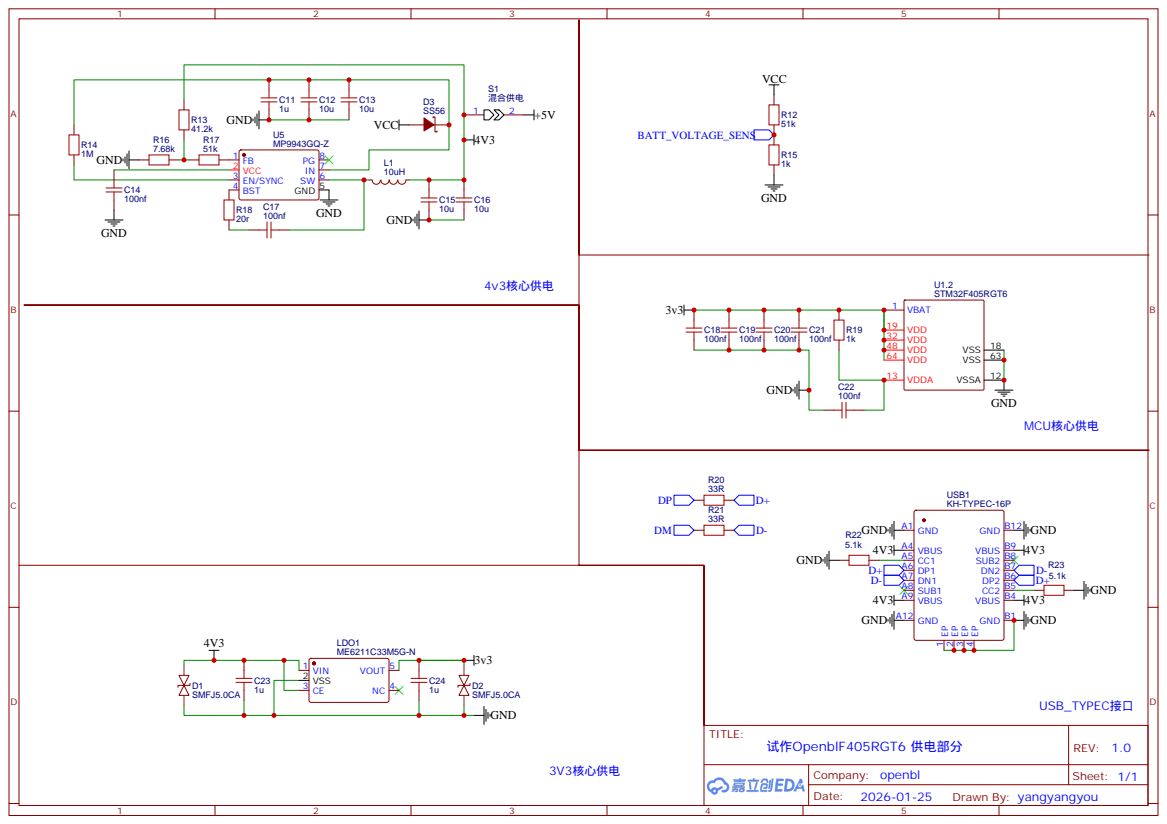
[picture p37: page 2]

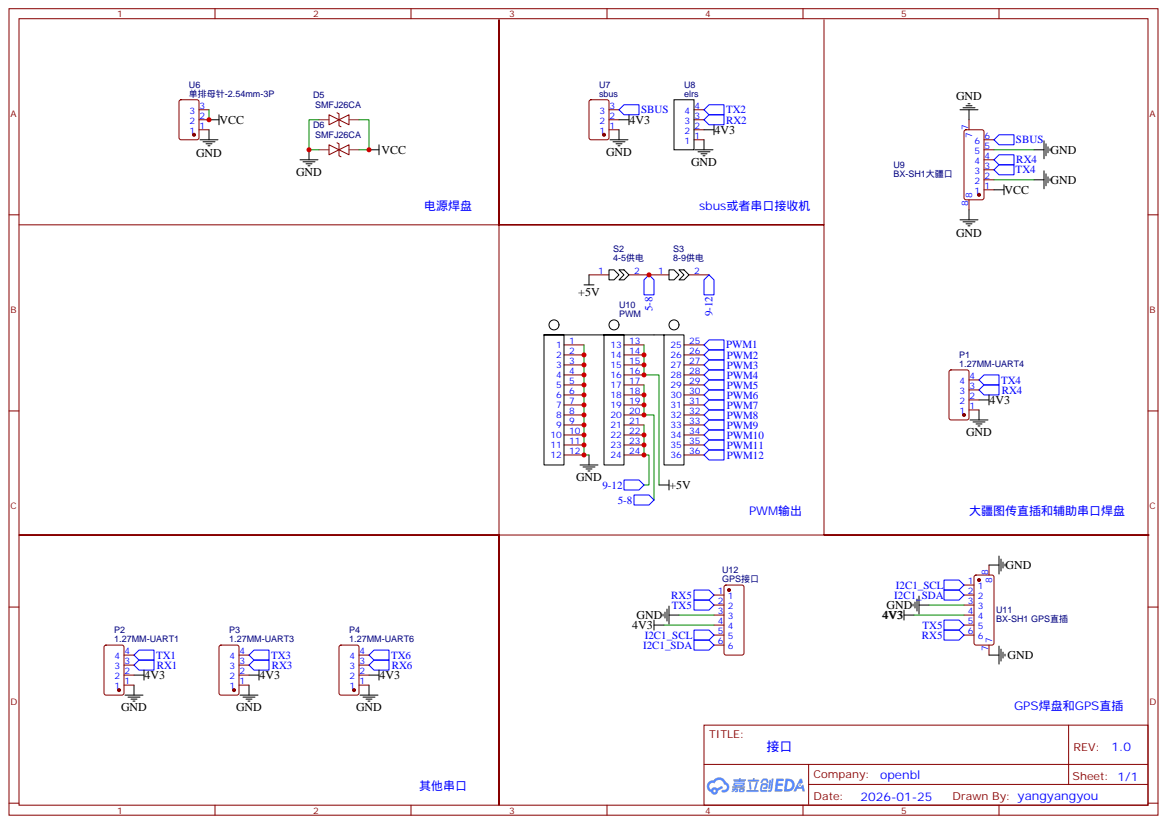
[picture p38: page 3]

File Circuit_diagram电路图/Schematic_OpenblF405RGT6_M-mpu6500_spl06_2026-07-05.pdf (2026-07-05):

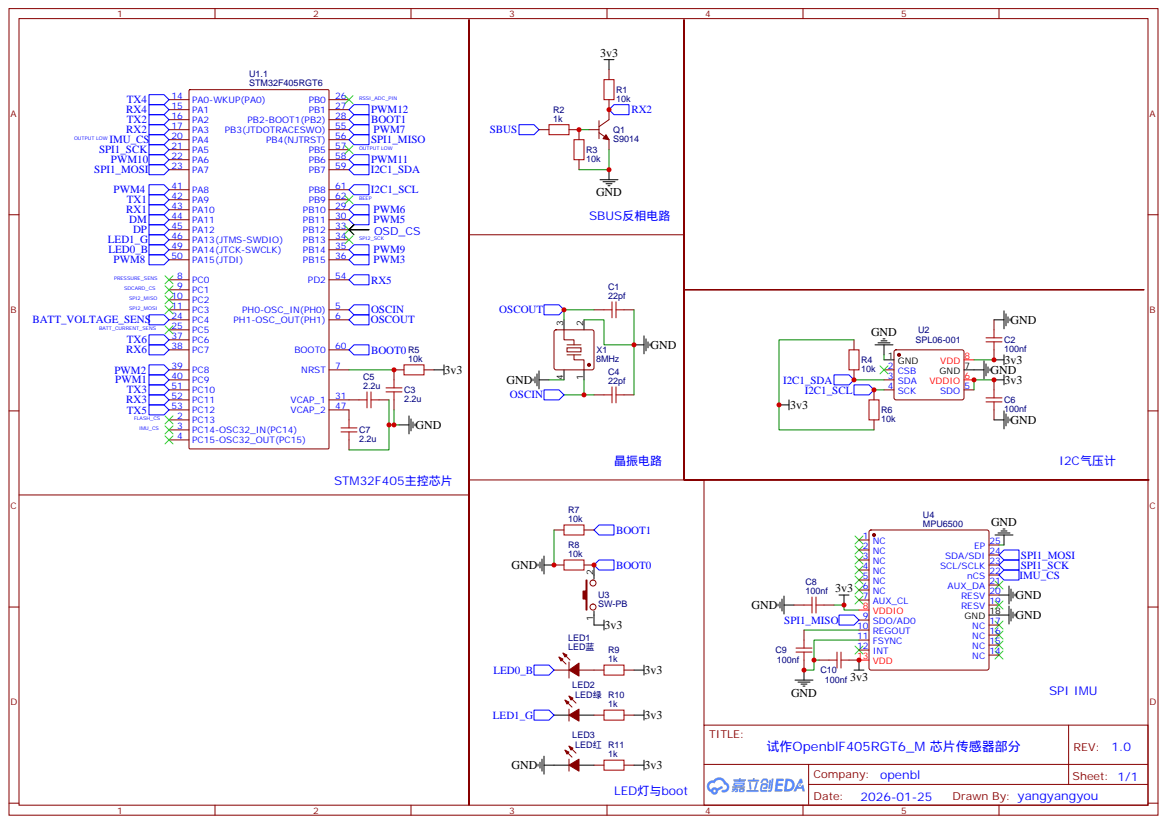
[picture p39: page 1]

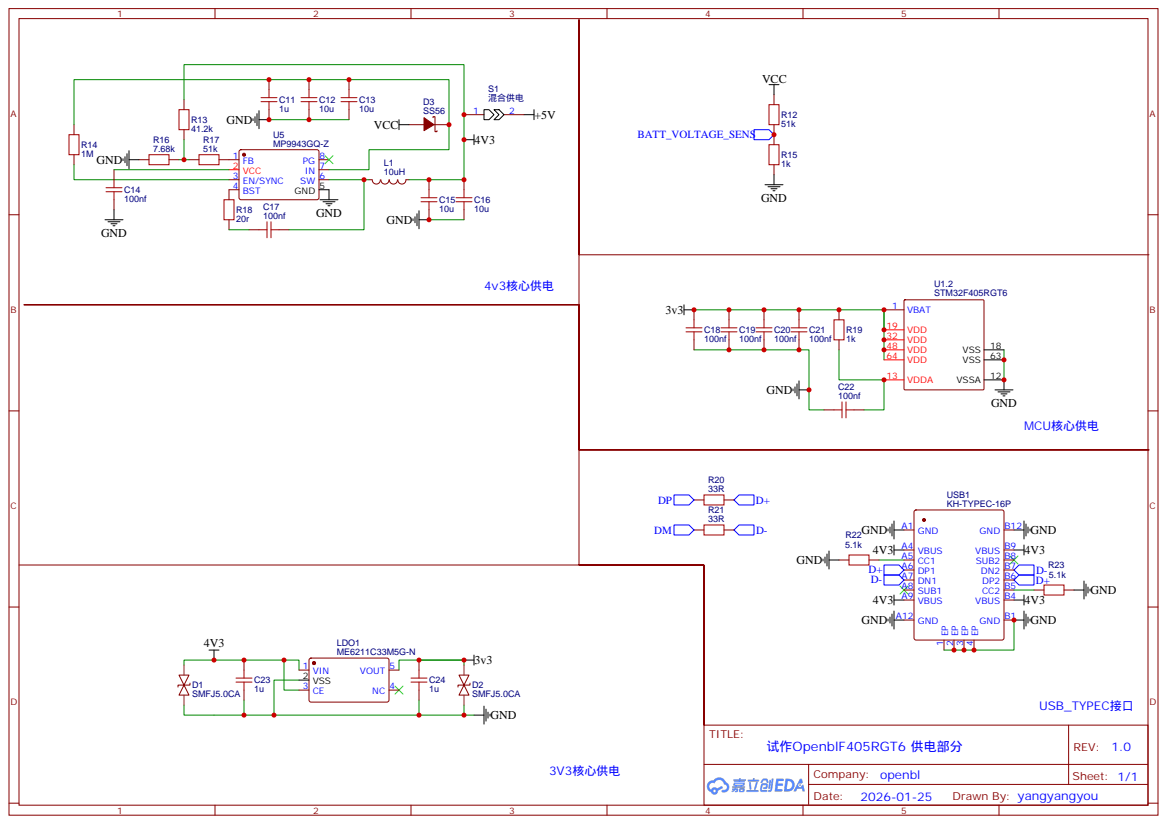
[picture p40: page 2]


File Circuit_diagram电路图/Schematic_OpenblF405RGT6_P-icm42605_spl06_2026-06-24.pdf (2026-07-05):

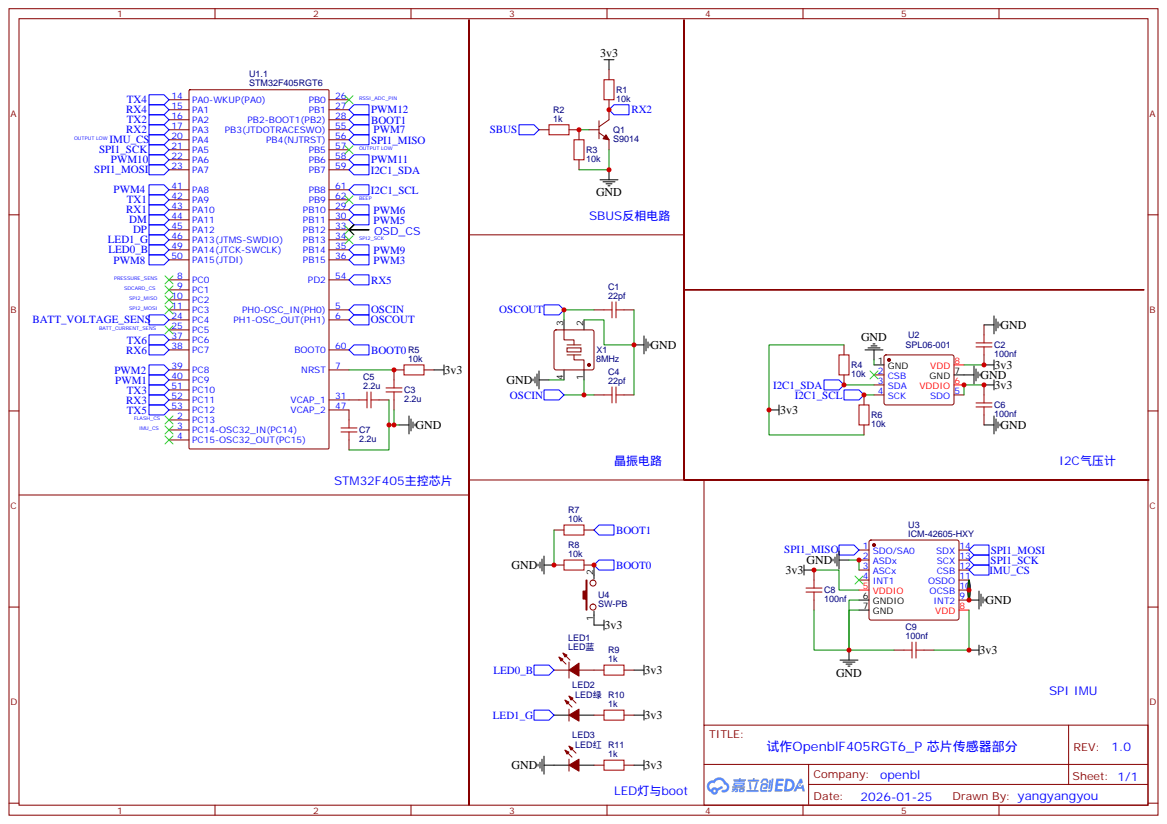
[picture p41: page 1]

ICM-42605-HXY
OCSB 10 OSDO 11 CSB 12 SCX 13 SDX 14

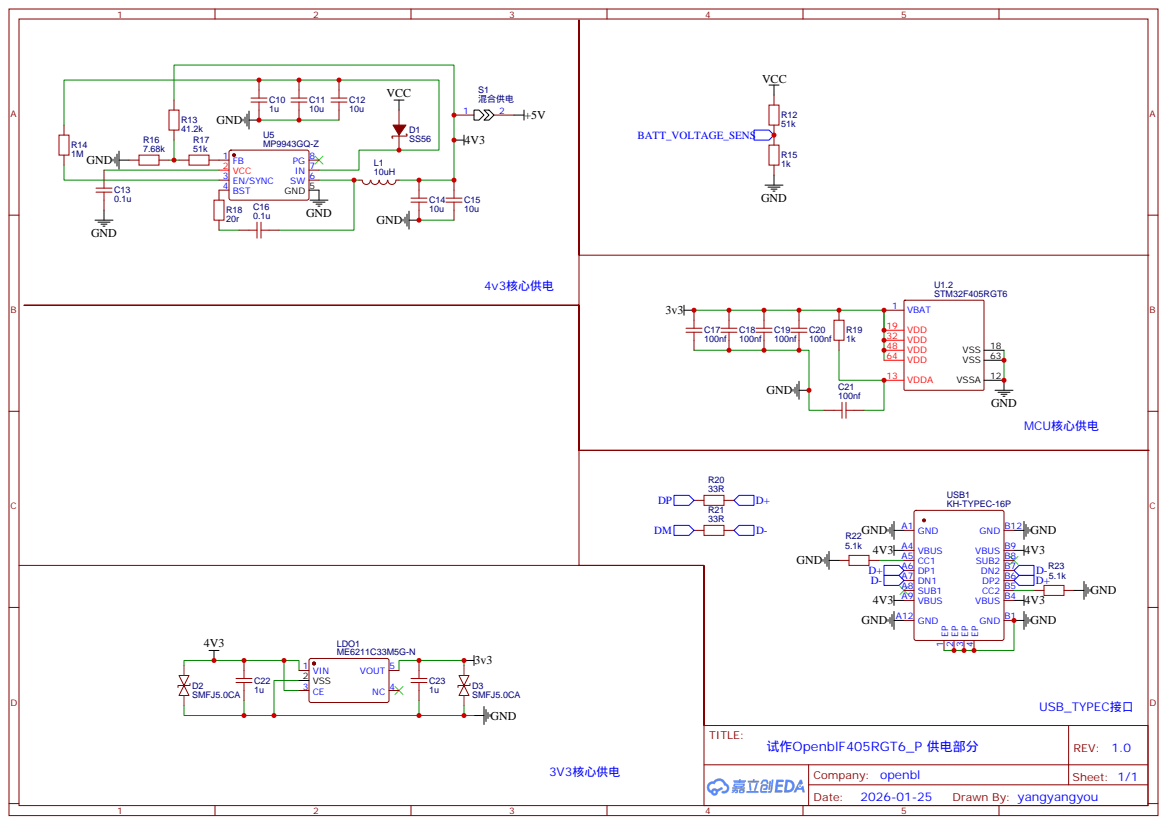
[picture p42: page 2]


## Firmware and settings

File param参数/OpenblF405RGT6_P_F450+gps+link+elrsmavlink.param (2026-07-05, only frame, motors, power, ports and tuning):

ATC_ANG_LIM_TC,1
ATC_ANG_PIT_P,4.5
ATC_ANG_RLL_P,4.5
ATC_ANG_YAW_P,4.5
ATC_ANGLE_BOOST,1
ATC_RAT_PIT_D,0.0036
ATC_RAT_PIT_D_FF,0
ATC_RAT_PIT_FF,0
ATC_RAT_PIT_FLTD,20
ATC_RAT_PIT_FLTE,0
ATC_RAT_PIT_FLTT,20
ATC_RAT_PIT_I,0.135
ATC_RAT_PIT_IMAX,0.5
ATC_RAT_PIT_P,0.135
ATC_RAT_PIT_PDMX,0
ATC_RAT_PIT_SMAX,0
ATC_RAT_RLL_D,0.0036
ATC_RAT_RLL_D_FF,0
ATC_RAT_RLL_FF,0
ATC_RAT_RLL_FLTD,20
ATC_RAT_RLL_FLTE,0
ATC_RAT_RLL_FLTT,20
ATC_RAT_RLL_I,0.135
ATC_RAT_RLL_IMAX,0.5
ATC_RAT_RLL_P,0.135
ATC_RAT_RLL_PDMX,0
ATC_RAT_RLL_SMAX,0
ATC_RAT_YAW_D,0
ATC_RAT_YAW_D_FF,0
ATC_RAT_YAW_FF,0
ATC_RAT_YAW_FLTD,20
ATC_RAT_YAW_FLTE,2.5
ATC_RAT_YAW_FLTT,20
ATC_RAT_YAW_I,0.018
ATC_RAT_YAW_IMAX,0.5
ATC_RAT_YAW_P,0.18
ATC_RAT_YAW_PDMX,0
ATC_RAT_YAW_SMAX,0
ATC_RATE_FF_ENAB,1
ATC_RATE_P_MAX,0
ATC_RATE_R_MAX,0
ATC_RATE_Y_MAX,0
BATT_AMP_OFFSET,0
BATT_AMP_PERVLT,66.7
BATT_ARM_MAH,0
BATT_ARM_VOLT,0
BATT_CAPACITY,3300
BATT_CRT_MAH,0
BATT_CRT_VOLT,0
BATT_CURR_PIN,15
BATT_FS_CRT_ACT,0
BATT_FS_LOW_ACT,0
BATT_FS_VOLTSRC,0
BATT_LOW_MAH,0
BATT_LOW_TIMER,10
BATT_LOW_VOLT,10.5
BATT_MONITOR,3
BATT_OPTIONS,0
BATT_SERIAL_NUM,-1
BATT_VLT_OFFSET,0
BATT_VOLT_MULT,11.45
BATT_VOLT_PIN,14
BATT2_MONITOR,0
BATT3_MONITOR,0
BATT4_MONITOR,0
BATT5_MONITOR,0
BATT6_MONITOR,0
BATT7_MONITOR,0
BATT8_MONITOR,0
BATT9_MONITOR,0
FLTMODE_CH,6
FLTMODE_GCSBLOCK,0
FLTMODE1,0
FLTMODE2,0
FLTMODE3,0
FLTMODE4,2
FLTMODE5,0
FLTMODE6,5
FRAME_CLASS,1
FRAME_TYPE,1
INS_GYRO_FILTER,20
INS_HNTCH_ENABLE,0
MOT_BAT_CURR_MAX,0
MOT_BAT_CURR_TC,5
MOT_BAT_IDX,0
MOT_BAT_VOLT_MAX,0
MOT_BAT_VOLT_MIN,0
MOT_BOOST_SCALE,0
MOT_HOVER_LEARN,2
MOT_OPTIONS,0
MOT_PWM_MAX,2000
MOT_PWM_MIN,1000
MOT_PWM_TYPE,0
MOT_SAFE_DISARM,0
MOT_SAFE_TIME,1
MOT_SLEW_DN_TIME,0
MOT_SLEW_UP_TIME,0
MOT_SPIN_ARM,0.1
MOT_SPIN_MAX,0.95
MOT_SPIN_MIN,0.15
MOT_SPOOL_TIM_DN,0
MOT_SPOOL_TIME,0.5
MOT_THST_EXPO,0.65
MOT_THST_HOVER,0.125
MOT_YAW_HEADROOM,200
SERIAL0_BAUD,115
SERIAL0_PROTOCOL,2
SERIAL1_BAUD,460
SERIAL1_OPTIONS,0
SERIAL1_PROTOCOL,2
SERIAL2_BAUD,460
SERIAL2_OPTIONS,0
SERIAL2_PROTOCOL,-1
SERIAL3_BAUD,230
SERIAL3_OPTIONS,0
SERIAL3_PROTOCOL,5
SERIAL4_BAUD,230
SERIAL4_OPTIONS,0
SERIAL4_PROTOCOL,5
SERIAL5_BAUD,57
SERIAL5_OPTIONS,0
SERIAL5_PROTOCOL,-1
SERIAL6_BAUD,460
SERIAL6_OPTIONS,0
SERIAL6_PROTOCOL,2
SERVO1_FUNCTION,33
SERVO1_MAX,2000
SERVO1_MIN,1000
SERVO1_REVERSED,0
SERVO1_TRIM,1500
SERVO2_FUNCTION,34
SERVO2_MAX,2000
SERVO2_MIN,1000
SERVO2_REVERSED,0
SERVO2_TRIM,1500
SERVO3_FUNCTION,35
SERVO3_MAX,2000
SERVO3_MIN,1000
SERVO3_REVERSED,0
SERVO3_TRIM,1500
SERVO4_FUNCTION,36
SERVO4_MAX,2000
SERVO4_MIN,1000
SERVO4_REVERSED,0
SERVO4_TRIM,1500
SERVO5_FUNCTION,0
SERVO5_MAX,1900
SERVO5_MIN,1100
SERVO5_REVERSED,0
SERVO5_TRIM,1500
SERVO6_FUNCTION,0
SERVO6_MAX,1900
SERVO6_MIN,1100
SERVO6_REVERSED,0
SERVO6_TRIM,1500
SERVO7_FUNCTION,0
SERVO7_MAX,1900
SERVO7_MIN,1100
SERVO7_REVERSED,0
SERVO7_TRIM,1500
SERVO8_FUNCTION,0
SERVO8_MAX,1900
SERVO8_MIN,1100
SERVO8_REVERSED,0
SERVO8_TRIM,1500
SERVO9_FUNCTION,0
SERVO9_MAX,1900
SERVO9_MIN,1100
SERVO9_REVERSED,0
SERVO9_TRIM,1500

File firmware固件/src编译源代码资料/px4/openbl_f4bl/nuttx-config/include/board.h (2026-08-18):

/************************************************************************************
 * nuttx-configs/openbl_f4bl/include/board.h
 * include/arch/board/board.h
 *
 *   Copyright (C) 2012 Gregory Nutt. All rights reserved.
 *   Author: Gregory Nutt <gnutt@nuttx.org>
 *
 *   Copyright (c) 2018 PX4 Development Team. All rights reserved.
 *
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
 * 1. Redistributions of source code must retain the above copyright
 *    notice, this list of conditions and the following disclaimer.
 * 2. Redistributions in binary form must reproduce the above copyright
 *    notice, this list of conditions and the following disclaimer in
 *    the documentation and/or other materials provided with the
 *    distribution.
 * 3. Neither the name NuttX nor the names of its contributors may be
 *    used to endorse or promote products derived from this software
 *    without specific prior written permission.
 *
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
 ************************************************************************************/

#ifndef __CONFIG_OPENBL_F4BL_INCLUDE_BOARD_H
#define __CONFIG_OPENBL_F4BL_INCLUDE_BOARD_H

/************************************************************************************
 * Included Files
 ************************************************************************************/
#include "board_dma_map.h"

#include <nuttx/config.h>

#ifndef __ASSEMBLY__
# include <stdint.h>
#endif

#include "stm32_rcc.h"
#include "stm32_sdio.h"
#include "stm32.h"

/************************************************************************************
 * Definitions
 ************************************************************************************/

/* Clocking *************************************************************************/
/* The OpenblF405RGT6 board features a single 8MHz crystal.
 *
 * This is the canonical configuration:
 *   System Clock source           : PLL (HSE)
 *   SYSCLK(Hz)                    : 168000000    Determined by PLL configuration
 *   HCLK(Hz)                      : 168000000    (STM32_RCC_CFGR_HPRE)
 *   AHB Prescaler                 : 1            (STM32_RCC_CFGR_HPRE)
 *   APB1 Prescaler                : 4            (STM32_RCC_CFGR_PPRE1)
 *   APB2 Prescaler                : 2            (STM32_RCC_CFGR_PPRE2)
 *   HSE Frequency(Hz)             : 8000000      (STM32_BOARD_XTAL)
 *   PLLM                          : 8            (STM32_PLLCFG_PLLM)
 *   PLLN                          : 336          (STM32_PLLCFG_PLLN)
 *   PLLP                          : 2            (STM32_PLLCFG_PLLP)
 *   PLLQ                          : 7            (STM32_PLLCFG_PLLQ)
 *   Main regulator output voltage : Scale1 mode  Needed for high speed SYSCLK
 *   Flash Latency(WS)             : 5
 *   Prefetch Buffer               : OFF
 *   Instruction cache             : ON
 *   Data cache                    : ON
 *   Require 48MHz for USB OTG FS, : Enabled
 *   SDIO and RNG clock
 */

/* HSI - 16 MHz RC factory-trimmed
 * LSI - 32 KHz RC
 * HSE - On-board crystal frequency is 8MHz
 * LSE - 32.768 kHz
 */

#define STM32_BOARD_XTAL        8000000ul

#define STM32_HSI_FREQUENCY     16000000ul
#define STM32_LSI_FREQUENCY     32000
#define STM32_HSE_FREQUENCY     STM32_BOARD_XTAL
#define STM32_LSE_FREQUENCY     32768

/* Main PLL Configuration.
 *
 * PLL source is HSE
 * PLL_VCO = (STM32_HSE_FREQUENCY / PLLM) * PLLN
 *         = (8,000,000 / 8) * 336
 *         = 336,000,000
 * SYSCLK  = PLL_VCO / PLLP
 *         = 336,000,000 / 2 = 168,000,000
 * USB OTG FS, SDIO and RNG Clock
 *         =  PLL_VCO / PLLQ
 *         = 48,000,000
 */

#define STM32_PLLCFG_PLLM       RCC_PLLCFG_PLLM(8)
#define STM32_PLLCFG_PLLN       RCC_PLLCFG_PLLN(336)
#define STM32_PLLCFG_PLLP       RCC_PLLCFG_PLLP_2
#define STM32_PLLCFG_PLLQ       RCC_PLLCFG_PLLQ(7)

#define STM32_SYSCLK_FREQUENCY  168000000ul

/* AHB clock (HCLK) is SYSCLK (168MHz) */

#define STM32_RCC_CFGR_HPRE     RCC_CFGR_HPRE_SYSCLK  /* HCLK  = SYSCLK / 1 */
#define STM32_HCLK_FREQUENCY    STM32_SYSCLK_FREQUENCY
#define STM32_BOARD_HCLK        STM32_HCLK_FREQUENCY  /* same as above, to satisfy compiler */

/* APB1 clock (PCLK1) is HCLK/4 (42MHz) */

#define STM32_RCC_CFGR_PPRE1    RCC_CFGR_PPRE1_HCLKd4     /* PCLK1 = HCLK / 4 */
#define STM32_PCLK1_FREQUENCY   (STM32_HCLK_FREQUENCY/4)

/* Timers driven from APB1 will be twice PCLK1 */

#define STM32_APB1_TIM2_CLKIN   (2*STM32_PCLK1_FREQUENCY)
#define STM32_APB1_TIM3_CLKIN   (2*STM32_PCLK1_FREQUENCY)
#define STM32_APB1_TIM4_CLKIN   (2*STM32_PCLK1_FREQUENCY)
#define STM32_APB1_TIM5_CLKIN   (2*STM32_PCLK1_FREQUENCY)
#define STM32_APB1_TIM6_CLKIN   (2*STM32_PCLK1_FREQUENCY)
#define STM32_APB1_TIM7_CLKIN   (2*STM32_PCLK1_FREQUENCY)
#define STM32_APB1_TIM12_CLKIN  (2*STM32_PCLK1_FREQUENCY)
#define STM32_APB1_TIM13_CLKIN  (2*STM32_PCLK1_FREQUENCY)
#define STM32_APB1_TIM14_CLKIN  (2*STM32_PCLK1_FREQUENCY)

/* APB2 clock (PCLK2) is HCLK/2 (84MHz) */
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

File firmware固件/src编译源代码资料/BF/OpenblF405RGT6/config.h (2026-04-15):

/*
 * This file is part of Betaflight.
 *
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
 * See the GNU General Public License for more details.
 *
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
 * If not, see <http://www.gnu.org/licenses/>.
 */

#pragma once

#define FC_TARGET_MCU     STM32F405

#define BOARD_NAME        OpenblF405RGT6
#define MANUFACTURER_ID   OPBL

#define USE_GYRO
#define USE_ACC
#define USE_GYRO_SPI_ICM42688P
#define USE_ACC_SPI_ICM42688P
#define USE_GYRO_SPI_MPU6500
#define USE_ACC_SPI_MPU6500
#define USE_BARO_BMP280
#define USE_BARO_SPL06
#define USE_MAX7456
#define USE_FLASH
#define USE_FLASH_M25P16

#define BEEPER_PIN           PB9
#define MOTOR1_PIN           PC9
#define MOTOR2_PIN           PC8
#define MOTOR3_PIN           PB15
#define MOTOR4_PIN           PA8
#define MOTOR5_PIN           PB11
#define MOTOR6_PIN           PB10
#define MOTOR7_PIN           PB3
#define MOTOR8_PIN           PA15
#define SERVO1_PIN           PB14
#define SERVO2_PIN           PA6
#define SERVO3_PIN           PB6
#define RX_PPM_PIN           PA3
#define LED_STRIP_PIN        PB1
#define UART1_TX_PIN         PA9
#define UART2_TX_PIN         PA2
#define UART3_TX_PIN         PC10
#define UART4_TX_PIN         PA0
#define UART5_TX_PIN         PC12
#define UART6_TX_PIN         PC6
#define UART1_RX_PIN         PA10
#define UART2_RX_PIN         PA3
#define UART3_RX_PIN         PC11
#define UART4_RX_PIN         PA1
#define UART5_RX_PIN         PD2
#define UART6_RX_PIN         PC7
#define I2C1_SCL_PIN         PB8
#define I2C1_SDA_PIN         PB7
#define LED0_PIN             PA14
#define LED1_PIN             PA13
#define SPI1_SCK_PIN         PA5
#define SPI2_SCK_PIN         PB13
#define SPI1_SDI_PIN         PB4
#define SPI2_SDI_PIN         PC2
#define SPI1_SDO_PIN         PA7
#define SPI2_SDO_PIN         PC3
#define ADC_VBAT_PIN         PC4
#define ADC_RSSI_PIN         PB0
#define ADC_CURR_PIN         PC5
#define ADC_EXTERNAL1_PIN    PC0
#define SDCARD_SPI_CS_PIN    PC1
// #define PINIO1_PIN           PA4
// #define PINIO2_PIN           PB5
#define FLASH_CS_PIN         PC13
#define MAX7456_SPI_CS_PIN   PB12
// #define GYRO_1_EXTI_PIN      PC15
#define GYRO_1_CS_PIN        PA4

#define TIMER_PIN_MAPPING \
    TIMER_PIN_MAP( 0, MOTOR1_PIN, 2,  0) \
    TIMER_PIN_MAP( 1, MOTOR2_PIN, 2,  0) \
    TIMER_PIN_MAP( 2, MOTOR3_PIN, 1,  1) \
    TIMER_PIN_MAP( 3, MOTOR4_PIN, 1,  1) \
    TIMER_PIN_MAP( 4, MOTOR5_PIN, 1,  0) \
    TIMER_PIN_MAP( 5, MOTOR6_PIN, 1,  0) \
    TIMER_PIN_MAP( 6, MOTOR7_PIN, 1,  0) \
    TIMER_PIN_MAP( 7, MOTOR8_PIN, 1,  0) \
    TIMER_PIN_MAP( 8, SERVO1_PIN, 3, -1) \
    TIMER_PIN_MAP( 9, SERVO2_PIN, 2, -1) \
    TIMER_PIN_MAP(10, SERVO3_PIN, 1,  0) \
    TIMER_PIN_MAP(11, LED_STRIP_PIN, 2,  0) \
    TIMER_PIN_MAP(12, BEEPER_PIN, 2, -1) \
    TIMER_PIN_MAP(13, RX_PPM_PIN, 3, -1) \
    TIMER_PIN_MAP(14, UART2_TX_PIN, 2,  0)

#define ADC1_DMA_OPT                    1

#define MAG_I2C_INSTANCE                I2CDEV_1
#define USE_BARO
#define BARO_I2C_INSTANCE               I2CDEV_1
#define DEFAULT_CURRENT_METER_SOURCE    CURRENT_METER_ADC
#define DEFAULT_VOLTAGE_METER_SOURCE    VOLTAGE_METER_ADC
#define DEFAULT_VOLTAGE_METER_SCALE     110
#define DEFAULT_CURRENT_METER_SCALE     150
#define BEEPER_INVERTED
#define PINIO1_BOX 40
#define PINIO2_BOX 41
#define SYSTEM_HSE_MHZ                  8
#define DEFAULT_BLACKBOX_DEVICE         BLACKBOX_DEVICE_FLASH
#define MAX7456_SPI_INSTANCE            SPI1
#define FLASH_SPI_INSTANCE              SPI2

#define GYRO_1_SPI_INSTANCE             SPI1
#define GYRO_1_ALIGN                    CW180_DEG_FLIP

#define SERIALRX_UART                   SERIAL_PORT_USART2
#define DEFAULT_RX_FEATURE              FEATURE_RX_SERIAL

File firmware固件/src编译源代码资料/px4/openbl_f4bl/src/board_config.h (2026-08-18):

/****************************************************************************
 *
 *   Copyright (c) 2018, 2014 PX4 Development Team. All rights reserved.
 *
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
 * 1. Redistributions of source code must retain the above copyright
 *    notice, this list of conditions and the following disclaimer.
 * 2. Redistributions in binary form must reproduce the above copyright
 *    notice, this list of conditions and the following disclaimer in
 *    the documentation and/or other materials provided with the
 *    distribution.
 * 3. Neither the name PX4 nor the names of its contributors may be
 *    used to endorse or promote products derived from this software
 *    without specific prior written permission.
 *
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
 ****************************************************************************/

/**
 * @file board_config.h
 *
 * openbl_f4bl internal definitions - based on verified APM OpenblF405RGT6 hwdef.dat
 */

#pragma once

/****************************************************************************************************
 * Included Files
 ****************************************************************************************************/

#include <px4_platform_common/px4_config.h>
#include <nuttx/compiler.h>
#include <stdint.h>

/****************************************************************************************************
 * Definitions
 ****************************************************************************************************/
/* Configuration ************************************************************************************/

/* openbl_f4bl GPIOs ********************************************************************************/
/* LEDs */
/* PA14 - Blue (ACT), active LOW */
/* PA13 - Green (B/E), active LOW */
#define GPIO_LED1       (GPIO_OUTPUT|GPIO_PUSHPULL|GPIO_SPEED_50MHz|GPIO_OUTPUT_CLEAR|GPIO_PORTA|GPIO_PIN14)
#define GPIO_LED_BLUE   GPIO_LED1

#define GPIO_LED2       (GPIO_OUTPUT|GPIO_PUSHPULL|GPIO_SPEED_50MHz|GPIO_OUTPUT_CLEAR|GPIO_PORTA|GPIO_PIN13)
#define GPIO_LED_GREEN  GPIO_LED2

#define BOARD_OVERLOAD_LED     LED_BLUE
#define BOARD_OVERLOAD_LED2    LED_GREEN

#define FLASH_BASED_PARAMS

/*
 * ADC channels
 *
 * These are the channel numbers of the ADCs of the microcontroller that can be used by the Px4 Firmware in the adc driver
 * PC4 = BATT_VOLTAGE_SENS (ADC1 Ch14)
 * PC5 = BATT_CURRENT_SENS (ADC1 Ch15)
 * PB0 = RSSI_ADC_PIN      (ADC1 Ch8)
 * PC0 = PRESSURE_SENS     (ADC1 Ch10)
 */
#define ADC_CHANNELS (1 << 8) | (1 << 10) | (1 << 14) | (1 << 15)

#define ADC_BATTERY_VOLTAGE_CHANNEL  14
#define ADC_BATTERY_CURRENT_CHANNEL  15
#define ADC_RC_RSSI_CHANNEL          8
#define ADC_AIRSPEED_VOLTAGE_CHANNEL 10

/* User GPIOs
 *
 * PWM output GPIOs matching APM OpenblF405RGT6 hwdef.dat:
 *   PC9  TIM8_CH4   TIM8  PWM(1)  GPIO(50)
 *   PC8  TIM8_CH3   TIM8  PWM(2)  GPIO(51)
 *   PB15 TIM1_CH3N  TIM1  PWM(3)  GPIO(52)
 *   PA8  TIM1_CH1   TIM1  PWM(4)  GPIO(53)
 *   PB11 TIM2_CH4   TIM2  PWM(5)  GPIO(54)
 *   PB10 TIM2_CH3   TIM2  PWM(6)  GPIO(55)
 *   PB3  TIM2_CH2   TIM2  PWM(7)  GPIO(56)
 *   PA15 TIM2_CH1   TIM2  PWM(8)  GPIO(57)
 *   PB14 TIM12_CH1  TIM12 PWM(9)  GPIO(58) NODMA
 *   PA6  TIM13_CH1  TIM13 PWM(10) GPIO(59) NODMA
 *   PB6  TIM4_CH1   TIM4  PWM(11) GPIO(60) NODMA
 *   PB1  TIM3_CH4   TIM3  PWM(12) GPIO(61)
 */

#define _MK_GPIO_INPUT(def) (((def) & (GPIO_PORT_MASK | GPIO_PIN_MASK)) | (GPIO_INPUT|GPIO_PULLUP))

#define GPIO_GPIO0_INPUT             _MK_GPIO_INPUT(GPIO_TIM8_CH4IN_1)
#define GPIO_GPIO1_INPUT             _MK_GPIO_INPUT(GPIO_TIM8_CH3IN_1)
#define GPIO_GPIO2_INPUT             _MK_GPIO_INPUT(GPIO_TIM1_CH3N_2)
#define GPIO_GPIO3_INPUT             _MK_GPIO_INPUT(GPIO_TIM1_CH1IN_1)

#define _MK_GPIO_OUTPUT(def) (((def) & (GPIO_PORT_MASK | GPIO_PIN_MASK)) | (GPIO_OUTPUT|GPIO_PUSHPULL|GPIO_SPEED_2MHz|GPIO_OUTPUT_CLEAR))

#define GPIO_GPIO0_OUTPUT            _MK_GPIO_OUTPUT(GPIO_TIM8_CH4OUT_1)
#define GPIO_GPIO1_OUTPUT            _MK_GPIO_OUTPUT(GPIO_TIM8_CH3OUT_1)
#define GPIO_GPIO2_OUTPUT            _MK_GPIO_OUTPUT(GPIO_TIM1_CH3N_2)
#define GPIO_GPIO3_OUTPUT            _MK_GPIO_OUTPUT(GPIO_TIM1_CH1OUT_1)
#define GPIO_GPIO4_OUTPUT            _MK_GPIO_OUTPUT(GPIO_TIM2_CH4OUT_2)
#define GPIO_GPIO5_OUTPUT            _MK_GPIO_OUTPUT(GPIO_TIM2_CH3OUT_2)
#define GPIO_GPIO6_OUTPUT            _MK_GPIO_OUTPUT(GPIO_TIM2_CH2OUT_2)
#define GPIO_GPIO7_OUTPUT            _MK_GPIO_OUTPUT(GPIO_TIM2_CH1OUT_2)
#define GPIO_GPIO8_OUTPUT            _MK_GPIO_OUTPUT(GPIO_TIM12_CH1OUT_2)
#define GPIO_GPIO9_OUTPUT            _MK_GPIO_OUTPUT(GPIO_TIM13_CH1OUT_1)
#define GPIO_GPIO10_OUTPUT           _MK_GPIO_OUTPUT(GPIO_TIM4_CH1OUT_1)
#define GPIO_GPIO11_OUTPUT           _MK_GPIO_OUTPUT(GPIO_TIM3_CH4OUT_1)

/* USB OTG FS
 *
 * PC5 OTG_FS_VBUS VBUS sensing
 */
//#define GPIO_OTGFS_VBUS     (GPIO_INPUT|GPIO_FLOAT|GPIO_SPEED_100MHz|GPIO_OPENDRAIN|GPIO_PORTC|GPIO_PIN5)

/* PWM */
#define BOARD_NUM_IO_TIMERS 3
#define DIRECT_PWM_OUTPUT_CHANNELS      4
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

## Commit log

2026-04-15 初始化仓库
    [STM32F405_OpenblF405RGT6.STL, STM32F405_OpenblF405RGT6加固.STL]
2026-07-05 推送新版飞控板卡（MINI）到仓库、新增入门说明的PPT
    [OpenblF405RGT6_P_F450+gps+link+elrsmavlink.param]
2026-07-05 重命名 P3.png 为 p3.png
2026-07-14 新增焊接用钢网框图纸Add steel mesh frame drawings for welding
    [钢网框4-4.STL, 钢网框4-8.STL]

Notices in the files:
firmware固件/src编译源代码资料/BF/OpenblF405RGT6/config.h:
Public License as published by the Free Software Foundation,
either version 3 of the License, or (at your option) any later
